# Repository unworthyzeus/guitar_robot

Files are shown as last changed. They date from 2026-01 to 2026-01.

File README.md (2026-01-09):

# Firmware Robot Guitarrista (Versió "Barra de Trasts")

Firmware per a ESP32 per controlar un robot que toca la guitarra via MIDI per Bluetooth (BLE).
**Aquesta versió utilitza una arquitectura simplificada de 10 motors (Barres de Trast).**

## Visió Global del Sistema

```mermaid
graph TD
    subgraph "1. Capa Usuari"
        DAW["App Mobil / DAW<br>(Envia MIDI via Bluetooth)"]
    end

    subgraph "2. Capa Software (ESP32)"
        BLE[("Bluetooth Stack")]
        Logic["MidiHandler<br>(Gestió de Barres i Pua)"]
        HAL["HAL<br>(Control Servos)"]
        Driver["I2C Driver"]
        
        DAW -.-> BLE
        BLE --> Logic
        Logic -- "Activa Barra X" --> HAL
        Logic -- "Colpeja Corda Y" --> HAL
        HAL -- "SetPWM" --> Driver
    end

    subgraph "3. Capa Electronica"
        PSU["Font Alimentacio Externa<br>(5V/5A)"]
        Bus[("Bus I2C")]
        PCA1["PCA9685 ÚNIC<br>(10 canals usats)"]

        Driver -- "SDA/SCL" --> Bus
        Bus --> PCA1
        PSU ====> PCA1
    end

    subgraph "4. Capa Mecanica"
        direction TB
        subgraph "Barres (Trasts)"
            Bar1["Barra Trast 1"]
            Bar2["Barra Trast 2"]
            Bar3["Barra Trast 3"]
            Bar4["Barra Trast 4"]
        end
        subgraph "Pont (Pua)"
            Pluckers["6x Actuadors Pua"]
        end
    end

    subgraph "5. Capa Fisica"
        GuitarStrings["Guitarra"]
    end

    PCA1 ====> Bar1 & Bar2 & Bar3 & Bar4
    PCA1 ====> Pluckers
    Bar1 & Bar2 & Bar3 & Bar4 -- "Prem TOTES les cordes" --> GuitarStrings
    Pluckers -- "Colpeja corda individual" --> GuitarStrings
```

## Arquitectura Simplificada (10 Motors)
Aquest disseny utilitza el concepte de **"Cejilla Mòbil"**:
*   **4 Motors per als Trasts**: Cada motor mou una barra que prem el Trast 1, 2, 3 o 4 de **totes les cordes alhora**.
*   **6 Motors per a les pues**: Un per cada corda per fer-la sonar.

## Estratègia Musical (Com tocar acords?)

### ⚠️ La Limitació
El sistema de barres rectes implica que **totes les notes actives han d'estar al mateix trast** (o a l'aire).
*   Això fa **impossible** tocar acords oberts estàndards com el Do Major (C) o el Sol (G) amb afinació normal (EADGBE), ja que requereixen dits en trasts diferents (0, 1, 2, 3...) alhora.

### ✅ La Solució: Afinació Oberta (Open Tuning)
Per treure el màxim partit al robot, es recomana canviar l'afinació de la guitarra a **Open E** o **Open G**.
En una afinació oberta, tocar totes les cordes a l'aire ja fa un acord major.
*   **Barra Aixecada (0)**: Acord Base (Ex: Mi Major).
*   **Barra Trast 1**: Acord Fa Major.
*   **Barra Trast 2**: Acord Fa# Major.

Així pots tocar cançons senceres només movent la barra amunt i avall!

## Muntatge del Hardware

1.  **Microcontrolador**: ESP32 DevKit.
2.  **Controlador**: **1x** Placa PCA9685 (Adreça 0x40 per defecte).
3.  **Connexions PCA9685**:
    -   **Canals 0-5**: Motors de Pua (Corda 1 a 6).
    -   **Canals 6-9**: Motors de Barra (Trast 1 a 4).

### Esquema Elèctric

```mermaid
graph TD
    subgraph Power ["Font d'Alimentacio"]
    PSU[Font 5V/5A]
    end

    subgraph Controller [Controlador]
    ESP32[ESP32 DevKit]
    ESP32 -- "SDA (21)" --> Bus_SDA
    ESP32 -- "SCL (22)" --> Bus_SCL
    ESP32 -- "GND" --> Common_GND
    end

    subgraph Driver ["PCA9685 (Adreça 0x40)"]
    PCA[PCA9685]
    Bus_SDA --> PCA
    Bus_SCL --> PCA
    Common_GND --> PCA
    PSU -- "V+" --> PCA
    PCA -- "Ch 0-5" --> Plucks[6x Servos Pua]
    PCA -- "Ch 6-9" --> Bars[4x Servos Barra]
    end
```

## Compilació i Càrrega

1.  Obre la carpeta a VS Code (PlatformIO).
2.  Build & Upload.

## Dependències
- Adafruit PWM Servo Driver
- BLE-MIDI

# Disseny 3D
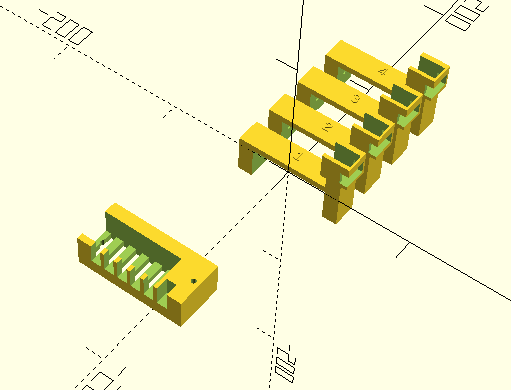
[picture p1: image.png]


## 🌐 Configuració WiFi i Afinació

El robot crea el seu propi punt d'accés WiFi per configurar-lo sense cables.

1.  Connecta't amb el mòbil/portàtil a la WiFi **GuitarBot_Setup**.
2.  La contrasenya és: **12345678**.
3.  Obre el navegador i ves a: **http://192.168.4.1**

Des d'allà podràs canviar en temps real entre **Standard**, **Open E**, **Open G**, etc. sense haver de tornar a carregar el codi.

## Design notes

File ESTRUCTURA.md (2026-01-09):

# Estructura del Codi del Guitar Robot

El projecte està dividit en mòduls per facilitar el manteniment i la neteja:

## 📁 `include/` (Headers)
*   `Config.h`: Tota la configuració de pins, angles dels servos i noms (Edit'l per calibrar).
*   `HAL.h`: Hardware Abstraction Layer. Defineix com ens comuniquem amb els motors.
*   `MidiHandler.h`: Gestió del Bluetooth MIDI.
*   `WebUI.h`: El servidor web de configuració.
*   `Tunings.h`: Base de dades d'afinacions i el gestor de canvi d'aquestes.

## 📁 `src/` (Lògica)
*   `main.cpp`: El cervell. Només inicialitza els mòduls i corre els seus `loop()`.
*   `HAL.cpp`: Implementació real dels motors (mou el PCA9685 i gestiona el temps no bloquejant).
*   `MidiHandler.cpp`: Rep les notes del mòbil i decideix quina corda i trast tocar (Lògica intel·ligent de barra).
*   `WebUI.cpp`: El codi del servidor web i tot el disseny HTML/JS que has vist.

## 📁 `design/` (3D)
*   `barre_unit.scad`: Peça per als trasts (imprimir x4).
*   `bridge_plucker.scad`: Peça per al pont (imprimir x1).
*   `guitar_bot_assembly.scad`: Visualització de com queda tot junt.

## 📁 Altres
*   `platformio.ini`: Configuració del projecte i llista de llibreries (Arduino, MIDI, etc.).
*   `test_ui.html`: Simulador per provar la web a l'ordinador sense el robot.

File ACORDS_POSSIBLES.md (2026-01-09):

# Guia d'Acords i Afinacions per al Robot (10 Motors)

Aquest robot utilitza un sistema de **Barra Rígida (Cejilla)**. Això vol dir que per fer un acord, totes les notes han d'estar alineades al mateix trast verticalment.

A continuació tens les millores estratègies d'afinació per treure-li suc.

---

## 1. MODO RECOMANAT: Open E Tuning
Afinació: **E - B - E - G# - B - E** (de greu a agut).
*Ideal per: Pop, Folk, Rock alegre. Acords majors complets.*

| Posició Barra | Acord resultant | Notes |
| :--- | :--- | :--- |
| **0 (Aixecada)** | **Mi Major (E)** | Totes a l'aire |
| **Trast 1** | **Fa Major (F)** | Barra al 1 |
| **Trast 2** | **Fa# Major (F#)** | Barra al 2 |
| **Trast 3** | **Sol Major (G)** | Barra al 3 |
| **Trast 4** | **Sol# Major (G#)** | Barra al 4 |

> **Truc**: Amb aquesta afinació, pots tocar la majoria de cançons pop de 3-4 acords (I-IV-V) només movent la barra.

---

## 2. EL MODO ROCKER: Drop D (Power Chords)
Afinació: **D - A - D - G - B - E** (Baixa la 6a corda un to).
*Ideal per: Rock dur, Metal, Punk. Només s'utilitzen les 3 cordes greus.*

En aquest mode, només has de fer sonar les **Cordes 6, 5 i 4**. Les agudes (1, 2, 3) no solen sonar bé amb la barra recta.

| Posició Barra | Power Chord (5) | Cordes a tocar |
| :--- | :--- | :--- |
| **0 (Aixecada)** | **D5** | 6, 5, 4 (a l'aire) |
| **Trast 1** | **Eb5** | 6, 5, 4 |
| **Trast 2** | **E5** | 6, 5, 4 |
| **Trast 3** | **F5** | 6, 5, 4 (famós acord de punk) |
| **Trast 4** | **F#5** | 6, 5, 4 |

---

## 3. EL MODO BLUES: Open G
Afinació: **D - G - D - G - B - D**.
*Ideal per: Rolling Stones, Blues amb Slide.*

| Posició Barra | Acord resultant |
| :--- | :--- |
| **0 (Aixecada)** | **Sol Major (G)** |
| **Trast 2** | **La Major (A)** |
| **Trast 4** | **Si Major (B)** | (El trast 3 seria A#/Bb) |

---

## 4. MODO STANDARD (E-A-D-G-B-E)
*Molt dolent per a acords amb aquest robot.*

A la guitarra estàndard, gairebé cap acord no utilitza una barra recta als primers 4 trasts excepte potser un fa menor estrany.
*   **Ús recomanat**: Només per tocar melodies d'una sola nota (puntejats / solos) on no importi l'harmonia vertical.

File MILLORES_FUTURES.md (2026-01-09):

# Millores i Evolució del Projecte

Un cop tinguis la versió bàsica (MVP) funcionant, aquí tens idees per portar el Guitar Robot al següent nivell.

## 1. Software i Firmware (Cost 0€)

### 🎛️ Calibració via WiFi (Molt Recomanat)
- **Problema**: Ara, per canviar l'angle d'un servo (si prem massa fort o fluix), has de modificar `Config.h` i tornar a pujar el codi. És lent.
- **Solució**: Crear una petita web (WebServer) dins l'ESP32.
- **Com funciona**: Et connectes amb el mòbil a "GuitarBot_Setup", obres una web i tens lliscadors (sliders) per ajustar cada servo en temps real. Els valors es guarden a la memòria permanent (EEPROM).

### 🎹 Sensibilitat (Velocity)
- **Problema**: Ara el robot sempre toca amb la mateixa força.
- **Solució**: Utilitzar el paràmetre `velocity` del MIDI.
- **Implementació**: Si la velocitat és 127 (màxim), la pua es mou més angle (`PLUCK_HIT_HARD`). Si és 40, es mou menys (`PLUCK_HIT_SOFT`). Això donarà "vida" a la música.

### 🎸 Mode "Strumming" (Rasgueo)
- **Problema**: El MIDI sol disparar notes individuals.
- **Solució**: Detectar acords i fer que els servos de les pues es disparin en cascada ràpida (Corda 6 -> 1) per simular un rasgueo de pua real, en lloc de sonar totes perfectament alhora com un piano.

## 2. Electrònica (Cost Baix/Mitjà)

### 🔋 Portabilitat (Bateries)
- Afegir un suport per a 2x Bateries 18650 (Li-Ion) i un mòdul BMS.
- Això permetria tocar al carrer sense endollar-lo a la paret.

### 📟 Pantalla d'Estat (OLED)
- Afegir una petita pantalla OLED I2C (0.96").
- **Funcions**: Mostrar la IP del WiFi, l'acord que està sonant (ex: "C Major") o l'estat de la connexió Bluetooth.

### 🌈 Llums Reactius (LEDs)
- Posar una tira de LED RGB (WS2812B) al costat de les barres.
- Il·luminar la barra que està prement el robot. Queda espectacular en directe/vídeos.

## 3. Mecànica (Cost Alt / Dificultat Alta)

### 🔇 Sistema d'Apagat (Damping)
- **El repte**: Una guitarra real necessita que paris les cordes amb la mà dreta perquè no es barregin els sons. El robot actual no sap "callar" una corda.
- **Solució**: Afegir una barra tova accionada per un servo extra que toqui lleugerament totes les cordes per silenciar-les (Mute).

### 🤖 Capo Automàtic (Eix Z)
- En lloc de tenir 4 barres fixes, tenir un sol robot que es mogui amunt i avall del mànec sobre uns rails (Motor Pas a Pas + Cargol sense fi).
- **Avantatge**: Pots tocar en qualsevol trast (0-12).
- **Desaventatge**: És lent canviant de posició (no pots fer solos ràpids) i mecànicament molt complex.

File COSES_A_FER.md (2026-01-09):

# Full de Ruta i Manual d'Assemblatge (Guitar Robot)

> **Arquitectura**: 10 Motors (4 Barres de Trast + 6 Pues)

## FASE 1: Aprovisionament (Components i Material)

### Electrònica
- [ ] **1x ESP32 DevKit V1**.
- [ ] **1x Mòdul PCA9685** (Controlador PWM 16 canals).
- [ ] **1x Font d'Alimentació 5V 5A (mínim)**.
  - *Tipus*: Font commutada (preferible) o "Power Brick".
  - *Cable*: Jack DC femella amb bornes o adaptador.
- [ ] **Cables**:
  - Cable 22AWG (vermell/negre) per alimentació.
  - Cables Jumper (Femella-Femella) per a l'ESP32.

### Actuadors
- [ ] **10x Servos MG90S (Metal Gear) - Versió 180º**.
  - *Molt Important*: Han de ser de **180 graus (Posicionals)**.
  - Els de 360 graus (rotació contínua) **NO** serveixen.
  - *Nota*: Compra'n 12-14 per tenir recanvis.
  - *Nota2*: Han de ser petits per cabre-hi

### Ferreteria i Diversos
- [ ] **Cargols M2 o M2.5** (per muntar els servos a les peces impreses).
- [ ] **Cargols M3 o M4 llargs** (per tancar l'abraçadora del mànec).
- [ ] **Goma EVA o Feltre** (adhesiu): Per posar a la cara interna de les abraçadores i protegir la fusta de la guitarra.
- [ ] **Goma duresa mitjana**: Per posar sota les "Barres de Trast" i que premin bé les cordes sense fer soroll metàl·lic.

---

## FASE 2: Impressió 3D

Tens els fitxers font a la carpeta `design/`. Utilitza OpenSCAD per generar els STL.

### A. Unitats de Barra (Trasts)
- [ ] **Generar STL**: Obre `design/barre_unit.scad`.
- [ ] **Imprimir X4 unitats**:
  - *Material*: PLA o PETG (millor PETG per resistència).
  - *Emplenat (Infill)*: 40% mínim (han de ser rígides).
  - *Suports*: Sí, necessaris per a l'arc.

### B. Unitat del Pont (Pues)
- [ ] **Generar STL**: Obre `design/bridge_plucker.scad`.
- [ ] **Imprimir X1 unitat**:
  - *Material*: PLA està bé.

---

## FASE 3: Muntatge Mecànic

1.  **Preparació Pesa Trasts**:
    - [ ] Enganxa el feltre/goma EVA a l'interior de l'arc del `BarreUnit`.
    - [ ] Munta el Servo MG90S a la torre lateral.
    - [ ] Fabrica la "Barra" física (pot ser un tros de plàstic imprès o un pal de gelat reforçat) i uneix-la al braç del servo. Enganxa-hi goma a sota.

2.  **Instal·lació al Mànec**:
    - [ ] Col·loca la **Unitat 1** sobre el Trast 1.
    - [ ] Col·loca la **Unitat 2** sobre el Trast 2.
    - [ ] Col·loca la **Unitat 3** sobre el Trast 3.
    - [ ] Col·loca la **Unitat 4** sobre el Trast 4.
    - [ ] Assegura les abraçadores amb els cargols M3/M4, però sense escanyar la guitarra.

3.  **Preparació Pesa Pont**:
    - [ ] Munta els 6 servos al `BridgePluckerArray`.
    - [ ] Posa'ls-hi un petit "dit" o pua al braç del servo.

---

## FASE 4: Cablejat Electrònic

Seguim l'esquema de pins del programa (`Config.h`):

**Connexions al PCA9685:**
| Servo | Port PCA |
|---|---|
| Pua C1 (Aguda) | 0 |
| Pua C2 | 1 |
| Pua C3 | 2 |
| Pua C4 | 3 |
| Pua C5 | 4 |
| Pua C6 (Greu) | 5 |
| **Barra Trast 1** | **6** |
| Barra Trast 2 | 7 |
| Barra Trast 3 | 8 |
| Barra Trast 4 | 9 |

**Connexions MCU:**
- ESP32 (GND/3V3/SDA/SCL) -> PCA9685.
- Font Alimentació (5V/GND) -> Borna Verda PCA9685.

---

## FASE 5: Calibració Software

1.  **Càrrega Inicial**:
    - [ ] Puja el firmware amb PlatformIO.
    - [ ] Tots les barres s'haurien d'aixecar (`BAR_UP`) i les pues centrar-se (`PLUCK_REST`).

2.  **Ajust d'Angles (`Config.h`)**:
    - Si les barres no baixen prou per prémer la corda, augmenta `BAR_DOWN`.
    - Si les barres baixen massa i xoquen amb la fusta, redueix `BAR_DOWN`.
    - Fes el mateix per a `PLUCK_HIT` fins que la pua toqui la corda netament.

3.  **Prova de So**:
    - [ ] Connecta el mòbil per Bluetooth ("GuitarBot_ESP32").
    - [ ] Envia una nota MIDI i gaudeix!

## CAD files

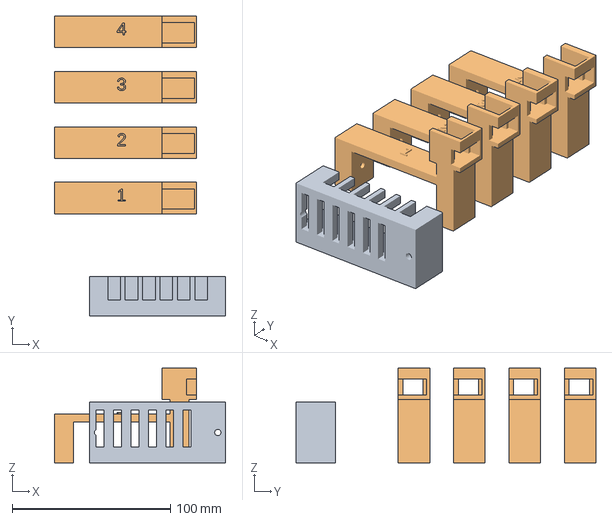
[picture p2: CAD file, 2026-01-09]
design/guitar_bot_assembly.3mf
108.3 x 189.6 x 60.0 mm
guitar_bot_assembly.stl_A
guitar_bot_assembly.stl_B

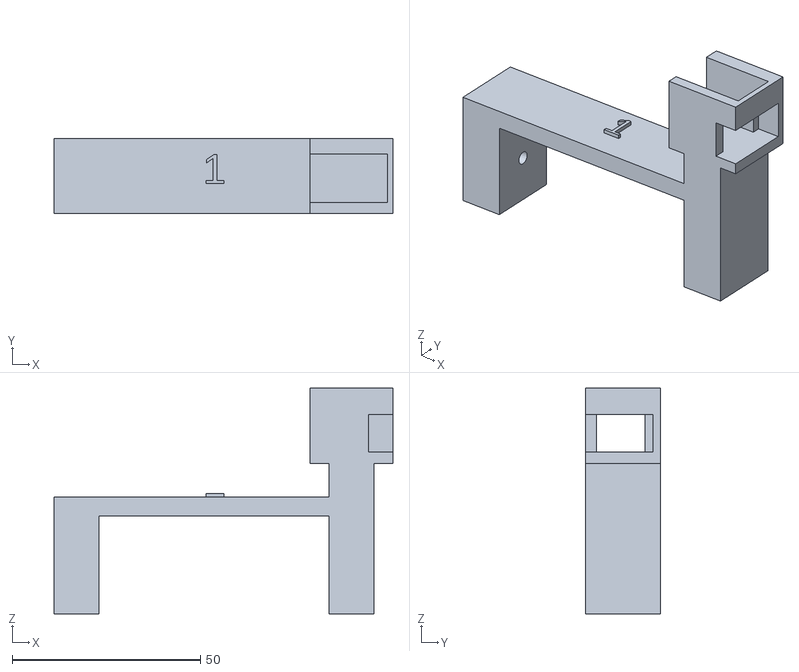
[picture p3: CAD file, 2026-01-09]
design/barre_unit.stl
90.0 x 20.0 x 60.0

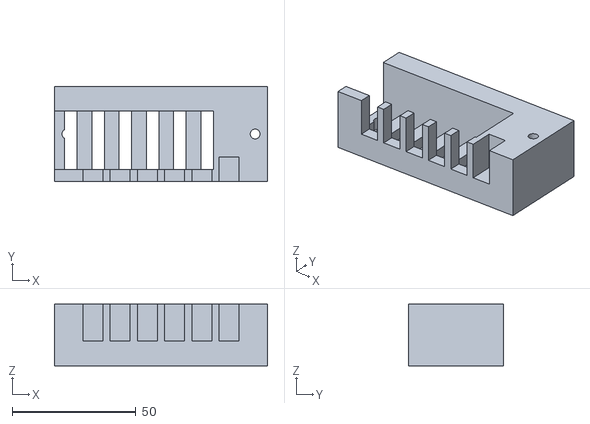
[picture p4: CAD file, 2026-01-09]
design/bridge_plucker.stl
86.0 x 38.5 x 25.0

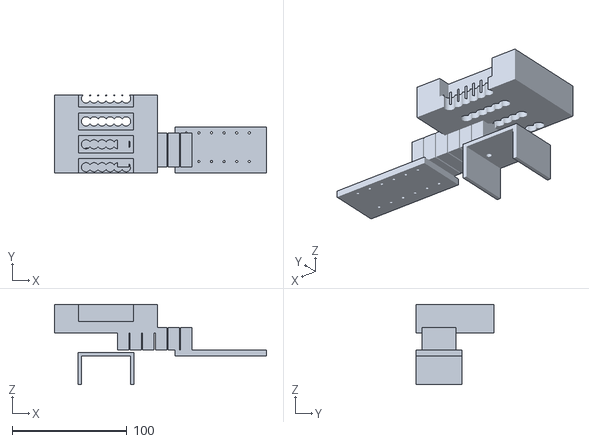
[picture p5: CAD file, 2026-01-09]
design/guitar_bot.stl
185.0 x 68.0 x 70.0

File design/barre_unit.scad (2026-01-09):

/*
    Barre Unit - Printable Part
    Print 4 copies of this file
*/

// --- Parameters ---
neck_width = 55;   // Width of guitar neck + padding
neck_height = 25;  // Thickness of guitar neck
servo_L = 23.5;    // Tolerance included
servo_W = 12.8;
servo_H = 23;

module ServoMG90S_Cutout() {
    cube([servo_L, servo_W, servo_H+10]);
    // Cable exit
    translate([servo_L-5, -5, 0]) cube([10, 20, 10]);
}

module BarreUnit(label="X") {
    base_w = neck_width + 30; 
    base_thick = 6;
    leg_width = 12;
    
    difference() {
        union() {
            // Main Arch
            translate([-base_w/2, 0, 0]) 
                cube([base_w, 20, base_thick]);
            
            // Left Leg
            translate([-base_w/2, 0, -neck_height]) 
                cube([leg_width, 20, neck_height]);
                
            // Right Leg + Servo Tower base
            translate([base_w/2 - leg_width, 0, -neck_height]) 
                cube([leg_width, 20, neck_height + 30]); // Taller for servo
                
            // Servo Tower Head
            translate([base_w/2 - leg_width - 5, 0, 15])
                cube([leg_width + 10, 20, 20]);
        }
        
        // Subtract Neck (Internal volume)
        translate([-base_w/2 + leg_width, -1, -neck_height-1])
            cube([base_w - 2*leg_width, 22, neck_height+2]);
            
        // Subtract Servo Hole (Side mounted)
        translate([base_w/2 - leg_width - 8, 3, 18])
            rotate([0, 0, 0])
            ServoMG90S_Cutout();
            
        // Mounting Screws for Clamp
        translate([-base_w/2 + leg_width/2, 10, -neck_height/2]) 
            rotate([0,90,0]) cylinder(d=3.5, h=base_w+10, center=true, $fn=20);
    }
    
    // Label
    color("White")
    translate([0, 8, base_thick])
        linear_extrude(1) text(label, size=8, halign="center");
}

// Render for printing
BarreUnit("1");

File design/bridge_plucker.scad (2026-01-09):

/*
    Bridge Plucker Array - Printable Part
    Print 1 copy of this file
*/

// --- Parameters ---
num_strings = 6;
string_spacing = 11; // Standard electric guitar spacing at bridge
servo_L = 23.5;
servo_W = 12.8;

module ServoMG90S_Cutout() {
    cube([servo_L, servo_W, 20]);
    // Cable hole
    translate([0, 0, -5]) cube([servo_L, 5, 20]);
}

module BridgePluckerArray() {
    total_w = num_strings * string_spacing + 20;
    total_d = servo_L + 15;
    total_h = 25;
    
    difference() {
        // Main Block
        translate([-total_w/2, 0, 0])
            cube([total_w, total_d, total_h]);
            
        // Servo Slots
        for (i = [0 : num_strings-1]) {
            // Calculate X pos relative to center
            x_pos = (i - (num_strings-1)/2) * string_spacing;
            
            translate([x_pos - servo_W/2, 5, 5])
                rotate([0,0,90]) // Rotate servos to face strings
                ServoMG90S_Cutout();
                
            // Actuator Arm Slot (Front)
            translate([x_pos - 4, -5, 10])
                cube([8, 15, 20]);
        }
        
        // Mounting Holes (To stick to guitar body)
        translate([-total_w/2 + 5, total_d/2, 0])
            cylinder(d=4, h=50, center=true, $fn=20);
        translate([total_w/2 - 5, total_d/2, 0])
            cylinder(d=4, h=50, center=true, $fn=20);
    }
}

// Render for printing
BridgePluckerArray();

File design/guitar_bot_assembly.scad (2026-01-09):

/*
    Guitar Robot - Full Assembly Visualization
    Use 'barre_unit.scad' and 'bridge_plucker.scad' for printing.
*/

use <barre_unit.scad>
use <bridge_plucker.scad>

// Parameters need to match included files or be re-declared if those files are standalone.
// For simplicity, we assume the included files provide modules.

// --- Assembly ---

// Show 4 Fret Bars spaced out
echo("Rendering Assembly...");

for (i=[0:3]) {
    translate([0, i * 35, 0])
        BarreUnit(str(i+1));
}

// Show Bridge Unit (Way back)
translate([-20, -150, 0])
    BridgePluckerArray();

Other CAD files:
design/guitar_bot_assembly.stl

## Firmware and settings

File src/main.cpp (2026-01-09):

#include <Arduino.h>
#include "Config.h"
#include "HAL.h"
#include "MidiHandler.h"
#include "WebUI.h"

void setup() {
    Serial.begin(115200);
    Serial.println("Starting Guitar Robot Firmware...");

    Serial.println("Initializing HAL...");
    HAL::init();

    Serial.println("Initializing MIDI...");
    MidiHandler::init();
    
    Serial.println("Initializing WebUI...");
    WebUI::init();

    Serial.println("Ready to Rock!");
}

void loop() {
    MidiHandler::loop();
    HAL::loop();
    WebUI::loop();
    delay(1); // Minimal delay
}

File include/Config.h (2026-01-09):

#pragma once
#include <Arduino.h>

// Guitar Configuration
#define NUM_STRINGS 6
#define MAX_FRETS 4 // Number of mechanical bars (1 to 4)

// MIDI Config
#define MIDI_NAME "GuitarBot_ESP32"

// Pin Definitions (PCA9685 Channels)
// New "Barre" Architecture:
// Channels 0-5: Pluckers for Strings 1-6
// Channels 6-9: Bars for Frets 1-4

#define PCA_ADDR 0x40 // Only 1 driver needed now
#define I2C_SDA 21
#define I2C_SCL 22

// Servo Parameters
#define SERVO_MIN 150
#define SERVO_MAX 600
#define PLUCK_REST 300   // Center position for plucker
#define PLUCK_HIT  400   // Hit position
#define BAR_UP     200   // Bar lift position
#define BAR_DOWN   400   // Bar press position

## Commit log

2026-01-09 Afegit disseny 3D aprox
    [guitar_bot.scad, guitar_bot.stl]
2026-01-09 actualitzat a model mes modular
    [barre_unit.scad, barre_unit.stl, bridge_plucker.scad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]
2026-01-09 Fixed guitar bot assembly scad
    [guitar_bot_assembly.scad, guitar_bot_assembly.stl]
2026-01-09 Especificat servos
    [guitar_bot_assembly.3mf]
